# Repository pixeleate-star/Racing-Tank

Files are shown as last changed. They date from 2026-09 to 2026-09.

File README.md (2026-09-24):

# ESP32 Racing Tank

This is my ESP32 based racing tank project made using an ESP32, FlySky FS-i6 transmitter and receiver, two BTS7960 motor drivers and two Johnson DC motors.

The tank uses a tracked/belt drive system, with one motor controlling each side. The ESP32 receives the control signals from the FS-i6 receiver and controls the left and right motors independently.

This allows the tank to move forward, backward, turn left and right, and also perform tank-style differential steering.

The project includes the CAD model, circuit connections, ESP32 code and the required setup to build and control the tank.







## features

- ESP32 as the main controller
- FlySky FS-i6 transmitter
- FlySky receiver
- Two BTS7960 motor drivers
- Two Johnson DC motors
- Tank/belt drive system
- Independent left and right motor control
- Differential steering
- Forward and backward movement
- Left and right turning
- Variable motor speed
- Wireless RC control
- CAD model included

## BOM – bill of materials

| component | quantity | price (USD) | total (USD) | purpose |
|---|:---:|---:|---:|---|
| [ESP32 development board](https://robu.in/product/esp-wroom-32-wifi-bluetooth-networking-smart-component-development-board/) | 1 | $4.49 | $4.49 | main controller |
| [FlySky FS-i6 + FS-iA6B receiver](https://robu.in/product/flysky-fs-i6-2-4g-6ch-ppm-rc-transmitter-with-fs-ia6b-receiver/) | 1 set | $65.10 | $65.10 | wireless controller and receiver |
| [BTS7960 motor driver](https://robu.in/product/double-bts7960-43a-h-bridge-high-power-stepper-motor-driver-module/) | 2 | $3.75 | $7.50 | controls the motors |
| [12V 600 RPM Johnson geared DC motor](https://robu.in/product/grade-a-quality-orange-12v-600-rpm-johnson-geared-dc-motor/) | 4 | $6.94 | $27.77 | drives the tracks |
| [Track belt](https://www.flyrobo.in/track-belt-2cm-width) | 4 | $1.57 | $6.27 | tank movement |
| [18650 3.7V 2600mAh Li-ion battery](https://robu.in/product/dmegc-inr18650-26e-3-7v-2600mah-li-ion-battery/) | 3 | $1.66 | $4.98 | power supply |
| [3 × 18650 battery holder](https://robu.in/product/black-plastic-storage-box-case-holder-battery-3-x-18650-cell-box-without-cover/) | 1 | $0.28 | $0.28 | battery holder |
| [LM2596 DC-DC buck converter](https://robu.in/product/lm2596s-with-smd-led-dc-dc-step-down-power-supply/) | 1 | $0.45 | $0.45 | regulates power for electronics |
| Jumper wires | as required | — | — | connections |
| 3D printed parts | as required | — | — | tank body and mounts |

## circuit connections



circuit diagram : https://app.cirkitdesigner.com/project/9e32e160-422e-4076-8aea-6d43e6693b43

The ESP32 receives the throttle and steering signals from the FlySky receiver.

The two BTS7960 motor drivers are used independently. One driver controls the left motor and the other controls the right motor.

### FS-iA6B receiver to ESP32

| FS-iA6B | ESP32 |
|---|---|
| CH1 | GPIO 18 |
| CH2 | GPIO 19 |
| VCC | 5V |
| GND | GND |

CH1 is used for steering and CH2 is used for throttle.

### Left BTS7960 to ESP32

| BTS7960 | ESP32 |
|---|---|
| RPWM | GPIO 25 |
| LPWM | GPIO 26 |
| R_EN | 5V |
| L_EN | 5V |
| VCC | 5V |
| GND | GND |

### Right BTS7960 to ESP32

| BTS7960 | ESP32 |
|---|---|
| RPWM | GPIO 27 |
| LPWM | GPIO 14 |
| R_EN | 5V |
| L_EN | 5V |
| VCC | 5V |
| GND | GND |

The R_IS and L_IS pins of both BTS7960 modules are not used.

### motors

| BTS7960 | motor |
|---|---|
| M+ / M- | left Johnson motor |
| M+ / M- | right Johnson motor |

One BTS7960 is used for the left motor and the other BTS7960 is used for the right motor.

If a motor rotates in the wrong direction, swap its motor wires or reverse the motor direction in the code.

## power connections

The motors are powered directly from the motor battery through the BTS7960 motor drivers.

The ESP32, receiver and BTS7960 logic are powered using a regulated 5V supply.

```text
Motor battery (+)
       |
       ├── Left BTS7960 B+
       |
       └── Right BTS7960 B+

Motor battery (-)
       |
       ├── Left BTS7960 B-
       |
       └── Right BTS7960 B-

5V buck converter
       |
       ├── ESP32 5V
       ├── Receiver VCC
       ├── Left BTS7960 VCC
       └── Right BTS7960 VCC
```

All grounds must be connected together.

```text
ESP32 GND
   |
   ├── Receiver GND
   ├── Left BTS7960 GND
   └── Right BTS7960 GND
```

Do not power the motors from the ESP32.

The BTS7960 motor power terminals and logic VCC are separate. The motor battery is connected to B+ and B-, while VCC is supplied with regulated 5V.

## how to build this

**step 1:** Get all the required components mentioned in the BOM.

**step 2:** Print or prepare the tank body using the CAD model included in this repository.

**step 3:** Mount the two Johnson motors and the track/belt mechanism on the chassis.

**step 4:** Install the left and right tracks and make sure they can move freely.

**step 5:** Mount the two BTS7960 motor drivers on the chassis.

**step 6:** Connect the left motor to the left BTS7960 and the right motor to the right BTS7960.

**step 7:** Connect the FS-iA6B receiver to the ESP32.

**step 8:** Connect the PWM and direction pins of both BTS7960 drivers to the ESP32.

**step 9:** Connect the motor battery and 5V buck converter according to the power connection diagram.

**step 10:** Make sure all grounds are connected together.

**step 11:** Bind the FS-i6 transmitter with the receiver.

**step 12:** Upload the ESP32 code.

**step 13:** Test the motor directions at low speed before running the tank at full speed.

## How the tank works????

The working of the tank is based on differential drive.

```text
FS-i6 transmitter
        ↓
FS-iA6B receiver
        ↓
ESP32
        ↓
Reads throttle + steering
        ↓
Motor mixing
        ↓
 ┌───────────────┐
 ↓               ↓
Left BTS7960   Right BTS7960
 ↓               ↓
Left motor     Right motor
 ↓               ↓
Left track     Right track
```

The receiver sends the throttle and steering values to the ESP32.

The ESP32 converts these values into left and right motor speeds.

The basic mixer is:

```text
Left motor  = Throttle + Steering
Right motor = Throttle - Steering
```

For example, when the throttle stick is pushed forward, both motors move forward.

When steering is applied, the speed of one motor is reduced while the other motor continues moving faster. This makes the tank turn.

The tank can also rotate in place by running the two tracks in opposite directions.

## motor mixing

The tank uses differential steering.

```text
Forward

Left track   →→→
Right track  →→→
```

```text
Backward

Left track   ←←←
Right track  ←←←
```

```text
Turn left

Left track   ←
Right track  →
```

```text
Turn right

Left track   →
Right track  ←
```

The exact motor direction depends on how the motors are physically mounted and connected.

If one side is moving in the opposite direction, swap the motor wires or invert that motor direction in the code.

## RC control

The FlySky FS-i6 is used as the wireless controller.

The receiver provides PWM signals to the ESP32.

```text
FS-i6
  ↓
Wireless signal
  ↓
FS-iA6B receiver
  ↓
CH1 + CH2
  ↓
ESP32
```

CH1 is used for steering and CH2 is used for throttle.

The ESP32 reads the pulse width from each channel and converts it into a motor control value.

The center value is approximately 1500 µs.

```text
1000 µs  → maximum one direction
1500 µs  → center / stop
2000 µs  → maximum opposite direction
```

The exact values can vary slightly depending on the transmitter and receiver settings.

## speed control

The ESP32 uses PWM to control the speed of the BTS7960 motor drivers.

The throttle determines the overall speed of the tank, while steering changes the speed difference between the two tracks.

The maximum speed can be limited in the code if the tank is too fast.

It is recommended to start with a lower speed and increase it gradually.

## Testing

Before driving the complete tank, test each part separately.

### 1. Receiver test

Check the CH1 and CH2 values in the serial monitor.

Move the FS-i6 sticks and make sure the values change correctly.

### 2. Left motor test

Test the left BTS7960 and left motor independently.

Check:

- forward direction
- backward direction
- speed control
- motor stopping

### 3. Right motor test

Repeat the same test for the right motor.

### 4. Differential drive test

After both motors work correctly, test:

- forward
- backward
- left
- right
- rotate left
- rotate right
- stop

Start with the tank lifted off the ground for the first motor test.

## CAD model

Screenshot 2026-09-23 at 9 23 01 PM



The CAD model contains the tank chassis, motor mounts, track system and mounting locations for the electronics.

The design can be modified depending on the motor size, battery and track dimensions.

## Things to keep in mind

1. All grounds should be connected together.
2. Do not power the motors from the ESP32.
3. Use a suitable battery for the Johnson motors.
4. Use a regulated 5V supply for the ESP32, receiver and BTS7960 logic.
5. Check both motor directions before installing the tracks.
6. Make sure the tracks can move freely.
7. Test the receiver before testing the motors.
8. Start with a low motor speed.
9. Keep the motor battery wiring thick enough for the motor current.
10. Make sure the BTS7960 modules have proper airflow.
11. Check the transmitter failsafe before driving the tank.
12. Stop the tank immediately if a motor or driver becomes excessively hot.
13. Make sure the battery voltage is suitable for the motors and BTS7960.
14. Secure the battery properly so it does not move while the tank is driving.

## Final result

This project was made to build a wireless RC racing tank using an ESP32 and a tracked drive system.

The two motors independently control the left and right tracks, allowing the tank to use differential steering. The FS-i6 provides wireless control while the ESP32 handles the receiver signals, motor mixing and speed control.

The main idea is simple:

```text
FS-i6
  ↓
Receiver
  ↓
ESP32
  ↓
Motor mixing
  ↓
2 × BTS7960
  ↓
2 × Johnson motors
  ↓
Left + right tracks
  ↓
Racing tank
```

## Demo

https://drive.google.com/file/d/1SPlf28peBSgvbxt1lPk7T9hTLhPETCV-/view?usp=sharing

This video shows the tank fully assembled and being controlled using the FS-i6 transmitter.

One correction from the earlier wiring: **R_EN and L_EN should not be treated as ESP32 3.3V outputs if your BTS7960 board requires 5V logic.** For in my case I've kept them at the regulated **5V** logic supply.

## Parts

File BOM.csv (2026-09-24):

component | quantity | price_usd | total_usd | purpose | link
ESP32 development board | 1 | 4.49 | 4.49 | main controller | https://robu.in/product/esp-wroom-32-wifi-bluetooth-networking-smart-component-development-board/
FlySky FS-i6 + FS-iA6B receiver | 1 set | 65.10 | 65.10 | wireless controller and receiver | https://robu.in/product/flysky-fs-i6-2-4g-6ch-ppm-rc-transmitter-with-fs-ia6b-receiver/
BTS7960 motor driver | 2 | 3.75 | 7.50 | controls the motors | https://robu.in/product/double-bts7960-43a-h-bridge-high-power-stepper-motor-driver-module/
12V 600 RPM Johnson geared DC motor | 4 | 6.94 | 27.77 | drives the tracks | https://robu.in/product/grade-a-quality-orange-12v-600-rpm-johnson-geared-dc-motor/
Track belt | 4 | 1.57 | 6.27 | tank movement | https://www.flyrobo.in/track-belt-2cm-width
18650 3.7V 2600mAh Li-ion battery | 3 | 1.66 | 4.98 | power supply | https://robu.in/product/dmegc-inr18650-26e-3-7v-2600mah-li-ion-battery/
3 x 18650 battery holder | 1 | 0.28 | 0.28 | battery holder | https://robu.in/product/black-plastic-storage-box-case-holder-battery-3-x-18650-cell-box-without-cover/
LM2596 DC-DC buck converter | 1 | 0.45 | 0.45 | regulates power for electronics | https://robu.in/product/lm2596s-with-smd-led-dc-dc-step-down-power-supply/
Jumper wires | as required |  |  | connections
3D printed parts | as required |  |  | tank body and mounts
TOTAL |  |  | 116.84

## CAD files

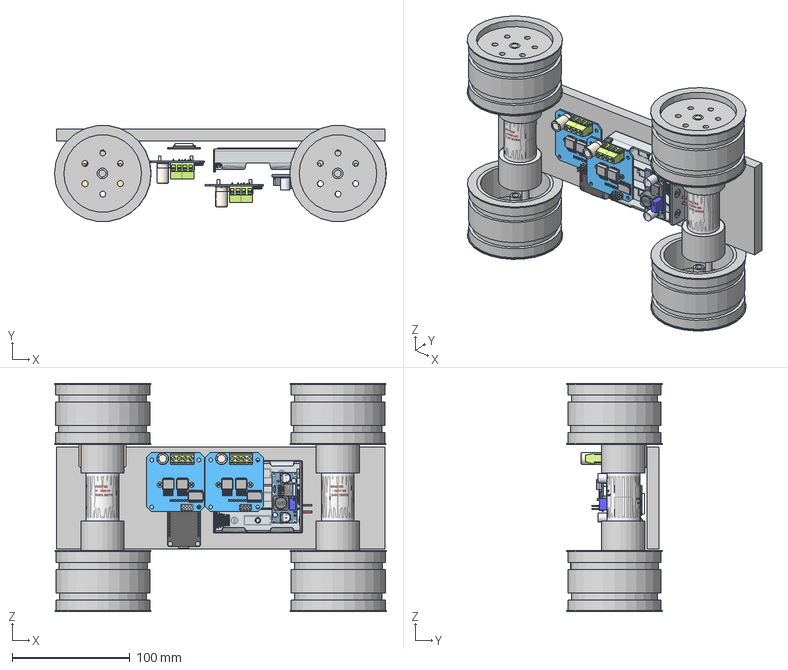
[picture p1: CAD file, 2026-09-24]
CAD/race tank.step
282.2 x 81.4 x 194.2 mm

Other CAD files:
CAD/race tank.f3z

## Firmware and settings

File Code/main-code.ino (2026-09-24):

#define CH1 18
#define CH2 19

#define L_RPWM 25
#define L_LPWM 26

#define R_RPWM 27
#define R_LPWM 14

int readCh(int pin) {
  int v = pulseIn(pin, HIGH, 25000);
  if (v < 900 || v > 2100) return 1500;
  return v;
}

void motor(int rpwm, int lpwm, int speed) {
  speed = constrain(speed, -255, 255);

  if (speed > 0) {
    analogWrite(rpwm, speed);
    analogWrite(lpwm, 0);
  } 
  else if (speed < 0) {
    analogWrite(rpwm, 0);
    analogWrite(lpwm, -speed);
  } 
  else {
    analogWrite(rpwm, 0);
    analogWrite(lpwm, 0);
  }
}

void setup() {
  pinMode(CH1, INPUT);
  pinMode(CH2, INPUT);

  pinMode(L_RPWM, OUTPUT);
  pinMode(L_LPWM, OUTPUT);
  pinMode(R_RPWM, OUTPUT);
  pinMode(R_LPWM, OUTPUT);

  motor(L_RPWM, L_LPWM, 0);
  motor(R_RPWM, R_LPWM, 0);
}

void loop() {
  int steering = readCh(CH1);
  int throttle = readCh(CH2);

  int s = map(steering, 1000, 2000, -255, 255);
  int t = map(throttle, 1000, 2000, -255, 255);

  if (abs(s) < 15) s = 0;
  if (abs(t) < 15) t = 0;

  int left = t + s;
  int right = t - s;

  left = constrain(left, -255, 255);
  right = constrain(right, -255, 255);

  motor(L_RPWM, L_LPWM, left);
  motor(R_RPWM, R_LPWM, right);

  delay(10);
}
